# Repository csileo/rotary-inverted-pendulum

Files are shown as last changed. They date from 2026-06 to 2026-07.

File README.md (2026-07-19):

# Rotary Inverted Pendulum

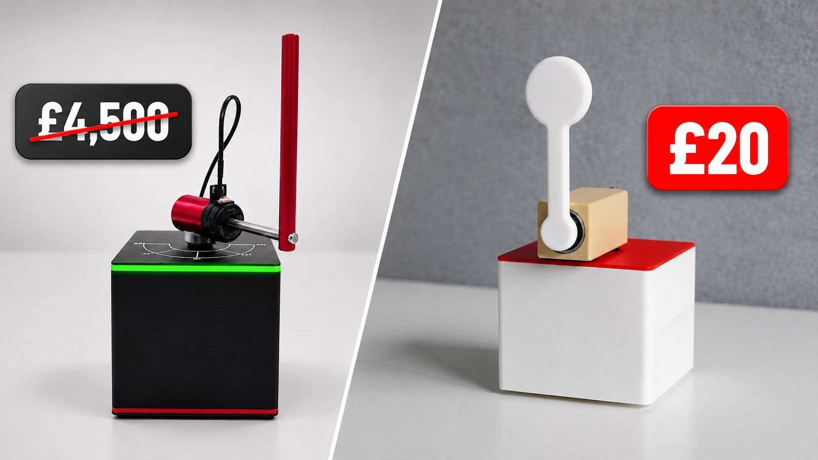
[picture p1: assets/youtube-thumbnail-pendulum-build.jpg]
Watch the build video (https://www.youtube.com/watch?v=rKChjuuR7K8)


A DIY rotary inverted pendulum you can print, solder, and train at home — for about **£20** in parts. It's an open, hackable take on the rigs you'd usually buy from a lab-equipment vendor (Quanser's [QUBE Servo 2](https://www.quanser.com/products/qube-servo-2) lists at around £4,500). The pendulum balances itself with a reinforcement-learning policy trained in simulation, fine-tuned on the real hardware, and quantised to run on an Arduino Nano.

## What's in this repo

| Directory | Contents |
| --- | --- |
| [`meshes/`](meshes), [`urdf/`](urdf) | 3D-printable STLs and the URDF model (single source of truth for pendulum geometry) |
| [`diagrams/`](diagrams) | Wiring diagrams and component photos |
| [`RotaryInvertedPendulum-arduino/`](RotaryInvertedPendulum-arduino) | Firmware — low-level server, hand-tuned PID, on-device RL controller |
| [`RotaryInvertedPendulum-python/`](RotaryInvertedPendulum-python) | Sim env, SAC training, system identification, real-hardware bridge, distillation and int8 export |
| [`RotaryInvertedPendulum-julia/`](RotaryInvertedPendulum-julia) | MPC/LQR exploration and MeshCat visualisation |
| [`docs/`](docs) | Build runbook, BOM, electronics design, RL stack documentation |

## Where to start

- **Build one** — [`docs/BOM.md`](docs/BOM.md), [`docs/electronics_design.md`](docs/electronics_design.md), [`docs/end_to_end_runbook.md`](docs/end_to_end_runbook.md)
- **Train a policy** — [`RotaryInvertedPendulum-python/README.md`](RotaryInvertedPendulum-python/README.md) walks through the simulation and training pipeline
- **Understand the RL stack** — [`docs/rl_transitions.md`](docs/rl_transitions.md), [`docs/domain_randomization.md`](docs/domain_randomization.md), [`docs/transport_delay.md`](docs/transport_delay.md), [`docs/quantisation.md`](docs/quantisation.md), [`docs/sysid_runbook.md`](docs/sysid_runbook.md)

## Branches

`main` has everything, including the trained checkpoints. Four narrower branches exist for handing off less than the whole thing:

| Branch | Contents |
| --- | --- |
| `2-full-no-models` | Everything except `models/` and `logs/` |
| `3-rl-ready` | Just the RL pipeline ([`RotaryInvertedPendulum-python/src/rl/`](RotaryInvertedPendulum-python/src/rl)) — run the training scripts as-is |
| `4-diy-rl` | Just the physical parameters ([`sysid_params.json`](RotaryInvertedPendulum-python/src/rl/sysid_params.json), [`docs/rig_geometry_parameters.md`](docs/rig_geometry_parameters.md)) — write your own sim and training from scratch |
| `demo` | Just enough to run the best checkpoint on the rig |

## Prefer to buy rather than build?

DIY kits run [$100–$200 on AliExpress](https://www.aliexpress.com/w/wholesale-rotary-inverted-pendulum.html); the Quanser QUBE Servo 2 mentioned above is around £4,500.

## Related work

- [Desktop Inverted Pendulum, build-its-inprogress](https://build-its-inprogress.blogspot.com/2016/08/desktop-inverted-pendulum-part-2-control.html) ([full series](https://build-its-inprogress.blogspot.com/search/label/Pendulum))
- [Furuta pendulum, dagor.dev](https://www.dagor.dev/blog/furuta-pendulum)
- [The Rotary Control Lab — Quanser brochure (PDF)](https://tecsolutions.us/sites/default/files/quanser/The%20Rotary%20Control%20Lab%20Brochure_4.pdf)
- [Survey paper, *Trans. Inst. Meas. Control*](https://journals.sagepub.com/doi/full/10.1177/00202940211035406)
- Video builds: [[1]](https://www.youtube.com/watch?v=2koXcs0IhOc), [[2]](https://www.youtube.com/watch?v=bY4t6yfBA24), [[3]](https://www.youtube.com/watch?v=VVQ-PGfJMuA)

## Acknowledgments

I would like to thank the following people for their contributions to this project:
- [Joe](https://github.com/spookycouch) for suggesting I try reinforcement learning with Stable Baselines 3, which kicked off the learned-control parts of this project.
- [Mykha](https://github.com/Mika412) for early discussions about this project over a beer in the park.
- [André](https://github.com/Esser50K), [Rafael](https://github.com/rkourdis), and [Vlad](https://github.com/VladimirIvan) for technical discussions, feedback, and support.
- [Vivek](https://github.com/svrkrishnavivek) for his invaluable help and feedback on the electronics of the system.
- [心诺 (Xinnuo)](https://github.com/XinnuoXu) for her company and support while working on this project.

Finally, I would like to thank the open-source community in general for providing the tools and resources that have also helped make this project possible.

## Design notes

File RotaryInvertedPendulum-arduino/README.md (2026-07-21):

# Arduino Sketches

This folder contains Arduino sketches for the Rotary Inverted Pendulum project.

## Prerequisites

Install [arduino-cli](https://arduino.github.io/arduino-cli/latest/installation/) and the AVR core:

```bash
arduino-cli core install arduino:avr
```

## Flashing Sketches

1. Find your Arduino's serial port:
   ```bash
   arduino-cli board list
   ```

2. Compile and flash (from repository root):
   ```bash
   arduino-cli compile --upload -p <PORT> --fqbn arduino:avr:nano:cpu=atmega328 RotaryInvertedPendulum-arduino/<SketchName>
   ```

   **Note:** This project uses `cpu=atmega328` (new bootloader). Do not use `cpu=atmega328old`.

## Sketches

### Test Sketches

These sketches are for testing individual hardware components.

#### TestHeartbeat

Blinks the LED in a double-pulse pattern. Useful for verifying the Arduino is powered and running.

- **Pattern:** ON(100ms)-OFF(100ms)-ON(100ms)-OFF(1000ms), repeating
- **Serial (115200):** Shows heartbeat count

**Use cases:** Quick hardware verification, power testing, bootloader check, debugging baseline.

#### TestEncoder

Tests the AS5600 magnetic encoder with multi-revolution tracking.

- **LED on** during setup, waits for magnet detection
- **LED flashes** when outputting readings
- **Serial (115200):** Outputs `pendulum_deg:value` (compatible with Serial Plotter)

**Troubleshooting:**
- "Waiting for magnet..." → Ensure magnet is positioned near the AS5600 sensor
- "Magnet strength too weak/strong" → Adjust magnet distance (~1-2mm)

#### TestMotor

Tests the stepper motor by oscillating between +90° and -90° positions.

- **LED on** during setup and during movement
- **Serial (115200):** Shows movement status
- Max speed set to 20,000 steps/sec (10x slower than production for visibility)

#### TestSerial

Measures serial round-trip time by echoing bytes.

- **LED on** during setup
- **LED flashes** on each received byte

Run the Julia measurement script:
```bash
julia --project=./RotaryInvertedPendulum-julia ./RotaryInvertedPendulum-arduino/TestSerial/measure_serial_rtt.jl <PORT> 115200
```

Expected output: ~2.5ms RTT, ~400 Hz max theoretical frequency.

#### TestServer

Simple server that tracks sine/cosine waves and responds to 'S' or 'C' byte requests.

```bash
julia --project=./RotaryInvertedPendulum-julia ./RotaryInvertedPendulum-arduino/TestServer/client.jl
```

### Production Sketches

#### LowLevelServer

Low-level server for computer-controlled operation. Arduino acts as a slave, receiving commands over serial (2,000,000 baud) from Julia/Python control code.

```bash
julia --project=./RotaryInvertedPendulum-julia ./RotaryInvertedPendulum-arduino/LowLevelServer/client.jl --visualise
```

**Before compiling**, copy the AS5600 backend matching your encoder module
from `LowLevelServer/hw_profiles/` to `LowLevelServer/hw_config.h`
(gitignored — no safe default, see that directory's files and
`docs/BOM.md` for which module you likely have):

```bash
cp LowLevelServer/hw_profiles/as5600_hailege_clone.h LowLevelServer/hw_config.h  # Hailege clone
# or
cp LowLevelServer/hw_profiles/as5600_seeed.h LowLevelServer/hw_config.h          # genuine Seeed module
```

`tools/pi_demo/flash_if_needed.py` refuses to compile without this file present.

#### PIDControl

Self-contained PID controller running entirely on Arduino. No computer required after flashing.

- **Serial (500000 baud):** Connect to view diagnostics and collect data
- **LED blink rate:** Fast (100ms) = waiting, Slow (500ms) = data output enabled

**Serial commands:**
- `P` - Toggle data output (CSV format at 100 Hz)
- `M` - Show magnet status
- `R` - Reset PID state

**Data collection:**
```bash
julia --project=./RotaryInvertedPendulum-julia ./RotaryInvertedPendulum-arduino/PIDControl/collect_and_plot.jl <PORT> [DURATION]
```

Example:
```bash
julia --project=./RotaryInvertedPendulum-julia ./RotaryInvertedPendulum-arduino/PIDControl/collect_and_plot.jl /dev/cu.usbserial-10 10
```

This collects data for the specified duration, generates plots, and saves CSV to `PIDControl/experiments/`.

See `PIDControl/TUNING_HISTORY.md` for tuning notes and `PIDControl/PIDControl.ino` header for architecture details.

## Hardware-in-the-Loop Testing

For automated testing with hardware connected:

```bash
./RotaryInvertedPendulum-arduino/scripts/monitor_serial.sh <PORT> <BAUD> <DURATION>
```

Example:
```bash
./RotaryInvertedPendulum-arduino/scripts/monitor_serial.sh /dev/cu.usbserial-10 115200 10
```

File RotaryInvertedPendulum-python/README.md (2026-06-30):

# RotaryInvertedPendulum-python

Python tooling for the rotary inverted pendulum: gamepad control,
system identification, and the RL pipeline (env, SAC trainer, deployment
client). See [`../RL_PLAN.md`](../RL_PLAN.md) for the broader plan.

## Environment setup

Single mamba env named `rotary-inverted-pendulum`, Python 3.12. Conda-forge
provides the scientific stack; pip provides MuJoCo / Gymnasium / SB3 / Torch
because they are more reliably installed from PyPI.

```bash
mamba create -n rotary-inverted-pendulum -y -c conda-forge python=3.12 numpy scipy
mamba activate rotary-inverted-pendulum

# Gamepad demo (older text-protocol script)
mamba install -y pygame pyserial

# RL + sysid extras (PyPI)
pip install pyserial 'numpy<2.3' mujoco gymnasium 'stable-baselines3[extra]'
```

Notes:
- `numpy<2.3` keeps compatibility with the conda-installed `scipy 1.14`. If
  you hit `_ARRAY_API not found` errors, an older `opencv-*` in
  `~/.local/lib/python3.12/site-packages/` is shadowing the env install.
  Run `pip install --user --upgrade opencv-contrib-python` to refresh it.
- macOS only: the MuJoCo viewer requires `mjpython` (a special launcher that
  handles Cocoa main-thread quirks). Install via the same `pip` and call
  `mjpython` instead of `python` for any script that opens a viewer.

## Control rate

This rig's canonical operating rate is **35 Hz** (28.6 ms per control step,
`max_action_delta_rad = 0.10` → 3.5 rad/s slew). It's the empirically-best
operating point on this hardware: 100 Hz pushes the policy into a noisy
"active correction" attractor where the motor swings ±0.5 rad even when
balanced; 30 Hz lacks slew authority for disturbance recovery; 35 Hz lands
in the calm-attractor side of the boundary at slew ~3.5 rad/s.

All `--control-freq` flags and the `control_freq_hz` constructor defaults
across `pendulum_env.py`, `real_env.py`, `async_control.py`, `train_sac.py`,
`finetune_async.py`, `eval_randomized.py`, `run_policy.py`, and `distill.py`
default to 35 Hz. Override only if you have a reason — see
[`../docs/control_rate_selection.md`](../docs/control_rate_selection.md) for
the principled rate-window argument and the calm-vs-active attractor data.

## End-to-end pipeline

For the full sysid → sim training → real-rig fine-tune → distill → flash
walkthrough with exact commands at each step, see
[`../docs/end_to_end_runbook.md`](../docs/end_to_end_runbook.md). Each step
is idempotent, so you can also dip into individual phases without re-running
the whole pipeline.

## Workflows

### Gamepad control (legacy)

Drives the Arduino's text-protocol firmware.

```bash
python src/gamepad_control.py
```

### System identification

Phase 0 of the RL plan. See [`../docs/sysid_runbook.md`](../docs/sysid_runbook.md)
for the full protocol. Quick start (with `LowLevelServer.ino` flashed):

```bash
cd src/rl
python sysid_wizard.py                  # full pipeline: collect + fit + plots
python sysid_wizard.py fit --in-dir ... # re-fit existing logs (no rig)
```

Re-run sysid whenever the rig changes (rebuilds, new bearings, motor envelope
adjustments, etc.) so `sysid_params.json` stays current and the simulator
reflects reality.

### RL training (Phase 1+)

Trains an SB3 SAC policy against the MuJoCo env parameterised by
`sysid_params.json`. Single env on CPU is the default; vectorised envs and
GPU are available via flags.

```bash
cd src/rl
python train_sac.py --total-steps 500000 --progress-bar
# View training curves
tensorboard --logdir runs/
```

Resume / evaluate:

```bash
python train_sac.py --resume runs/<run>/last.zip --total-steps 1000000
mjpython train_sac.py --eval runs/<run>/best_model.zip --eval-seconds 30
```

### Curriculum training (recommended)

Training from scratch with the full target DR (4-7 step delay, etc.) is
hard for SAC to converge — the policy gets stuck early. The curriculum
runner trains the policy in three stages of increasing DR difficulty,
each `--resume`-ing from the previous one's `best_model.zip`.

```bash
./curriculum_train.sh <run-name-prefix>
# example -> runs/<prefix>_stage1, _stage2, _stage3
```

Stage breakdown (defined in `curriculum_train.sh`):

| Stage | tau range | delay range | steps |
|---|---|---|---|
| 1 (easy) | 0–5 ms  | 0–2 steps | 100k |
| 2 (medium) | 0–10 ms | 2–5 steps | 100k |
| 3 (final)  | 0–10 ms | 4–7 steps | 100k |

The final stage 3 delay range matches the hardware's measured 5-step
transport delay at `MOTOR_ACCELERATION = 50k` and `Vref = 0.45 V`.
Override per-stage parameters via env vars (`SEED`, `STEPS_PER_STAGE`,
`DEVICE`).

### Evaluating a policy

Two complementary tools:

```bash
# Render a deterministic eval rollout in the MuJoCo viewer (mjpython on macOS)
mjpython train_sac.py --eval runs/<run>/best_model.zip --eval-seconds 30

# Stress-test the policy on N=20 randomly-physics-configured episodes.
# Reports a per-episode ✓/✗, a "solved" success rate, and the underlying
# DR sample (tau, delay) used for each episode. See the script docstring
# for the full success-criterion definition.
python eval_randomized.py runs/<run>/best_model.zip --n-episodes 20
```

### Trajectory logging + sim-to-real analysis

`run_policy.py --log <path>.npz` saves a step-level trajectory of the real-
hardware run. Two helper scripts then introspect that log to fit refined
sysid against the actively-driven dynamics (typically more informative
than the chirp/step sysid alone):

```bash
# Rough fit of effective transport delay and first-order tau against
# motor_target → motor_actual.
python analyze_run.py /tmp/policy_run.npz

# Replay the same logged action sequence in the sim and report motor /
# pendulum trajectory error vs the real device. Shows you how big the
# sim-to-real gap actually is on a real run.
python sim_vs_real.py /tmp/policy_run.npz
```

### Real-hardware deployment (Phase 3)

Drives the Arduino's `LowLevelServer.ino` binary protocol. Re-flash the
Arduino with `LowLevelServer` (sysid uses a different sketch). Always run
`--dry-run` first to verify the protocol; then run engaged with the rig
supervised.

```bash
cd src/rl
python run_policy.py --policy runs/<run>/best_model.zip \
    --port /dev/cu.usbserial-1130 --duration-s 5 --dry-run
python run_policy.py --policy runs/<run>/best_model.zip \
    --port /dev/cu.usbserial-1130 --duration-s 5
```

The deploy client clamps commanded position to ±125° (inside the ±135°
mechanical hard stops) and disengages the motor on exit / SIGTERM /
SIGINT.

## Layout

```
src/
  gamepad_control.py        # legacy text-protocol gamepad control
  rl/
    pendulum_env.py         # Gymnasium env (MuJoCo) parameterised from sysid_params.json
    train_sac.py            # SB3 SAC trainer with eval+checkpoint callbacks
    curriculum_train.sh     # 3-stage curriculum runner (easy -> full DR)
    eval_randomized.py      # N-episode randomized-env stress test (success-rate metric)
    run_policy.py           # Phase 3 deployment client (binary protocol)
    analyze_run.py          # Fits effective tau / transport delay from a run_policy log
    sim_vs_real.py          # Replays a logged action sequence in sim and compares
    lowlevel_client.py      # Python client for LowLevelServer.ino
    sysid_wizard.py         # Interactive sysid (collect/fit/validate-motor)
    sysid_core.py           # Sysid math (fits + parameter derivation)
    sysid_params.json       # Output of sysid_wizard.py (committed)
    freeswing_probe.py      # Standalone sim-vs-real validator
    sysid_runs/             # Per-session recordings (gitignored)
    runs/                   # Training artifacts (gitignored)
test/
  serial_test.py            # bare serial sanity check
  gamepad_test.py           # gamepad sanity check
```

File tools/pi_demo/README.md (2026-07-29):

# Auto-demo launcher

Makes the "power it on, walk away, it balances" demo robust to whatever
order the person plugs in the Pi/computer's power, the pendulum's 12V
adapter, and the Nano's USB cable in — and to arbitrary delay between each.
Nothing here assumes a particular order; each step waits out its own
precondition instead of failing on the first miss.

Runs unchanged on Linux, macOS, and Windows: the Nano is found by scanning
USB devices for its vid/pid (via `pyserial`'s `serial.tools.list_ports`)
instead of relying on a fixed `/dev/ttyUSB0`-style path or a udev rule, and
the launcher itself is plain Python rather than a shell script.

- **`flash_if_needed.py`** — waits for the Nano to show up, then compares
  a hash the firmware reports (`CMD_GET_FIRMWARE_VERSION`, baked in at
  compile time by
  `RotaryInvertedPendulum-arduino/LowLevelServer/gen_firmware_version.py`)
  against the local sketch source. Only runs `arduino-cli compile
  --upload` on a mismatch (or no response at all) — skips the ~15-30s
  flash cycle on every normal boot where the Nano already has the right
  firmware. Refuses to compile at all if
  `RotaryInvertedPendulum-arduino/LowLevelServer/hw_config.h` is missing
  (see that directory's `hw_profiles/`) — there's no safe default AS5600
  backend to guess.
- **`check_motor_power.py`** — the rig has no voltage sensing on the 12V
  rail, so this checks it indirectly: issue a small, brief acceleration
  pulse and confirm the AS5600 actually saw the motor move. If it didn't,
  the 12V adapter isn't plugged in (or there's a driver/Vref/enable wiring
  fault) — no new sensing hardware required.
- **`run_demo.py`** — orchestrates the above in order, waiting (not
  failing) at each step until its precondition is met, then runs the
  policy. Loops forever (10s pause between cycles by default) so a
  headless/no-network Pi keeps re-demoing without anyone reconnecting to
  restart it — Ctrl-C or SIGTERM (`systemctl stop`) is the only way out.
  Loads the policy once and keeps one serial connection to the Nano open
  across every cycle (calling `run_policy.py`'s `run_control_loop()`
  in-process instead of launching it as a fresh subprocess each time) —
  opening a new connection resets the Arduino, so reusing one avoids
  paying that reset repeatedly. The connection is only rediscovered /
  reflashed / reopened if something actually goes wrong (e.g. the Nano
  gets unplugged). Defaults `PENDULUM_POLICY` to the `.npz` (NumPy-only)
  build of the distilled student, not the `.pt`/torch one, so this
  process never has to import torch at all — see `numpy_student.py`.

## Which Nano to talk to

`pi_demo_common.py` resolves the vid/pid to search for like this:

1. `usb_config.json` in this directory, if it exists — this machine's own
   detected chip, written by `detect_usb_config.py`.
2. Otherwise, `usb_profiles/ch340.json` — the tracked reference default
   (confirmed in `docs/BOM.md` for both known builds).

`usb_config.json` is gitignored: it's a fact about this specific machine's
USB-serial chip, not something to share across forks. **The only way to
change which chip is used is to overwrite `usb_config.json`** — there is
no environment variable or CLI flag override, so it can never silently
drift out of sync with what's actually plugged in.

If your Nano uses a different chip than CH340/CH341, either add a new
`usb_profiles/<name>.json` (same two-key format) and copy it to
`usb_config.json`, or just run `detect_usb_config.py` with only the Nano
plugged in — it detects whichever single USB-serial device is present and
writes `usb_config.json` directly.

## Setup

1. Install Python deps (repo root `requirements.txt`, or the `demo`
   branch's copy if this is a demo-only checkout) and make sure
   `arduino-cli` is on `PATH` for the flash step.
2. Run `python detect_usb_config.py` once, with only the Nano plugged in
   (skip this if your chip already matches `usb_profiles/ch340.json`).
3. Make sure `RotaryInvertedPendulum-arduino/LowLevelServer/hw_config.h`
   is set up for your AS5600 module (see that directory's README/comments).
4. Run it: `python run_demo.py`. Wire it to whatever "on demand" trigger
   you want — a systemd service on the Pi, a Scheduled Task on Windows, a
   physical button via a GPIO watcher, cron, etc. This repo doesn't
   prescribe one; the script is a plain foreground process that loops
   forever (see above), blocking until Ctrl-C/SIGTERM.

## Environment variables

All optional — see `run_demo.py` for the exact defaults. None of these
select which Nano to talk to (see above) — only what to run once it's found.

| Variable | Meaning |
|---|---|
| `PENDULUM_POLICY` | Path to the `.zip`/`.pt`/`.npz` checkpoint to run |
| `PENDULUM_FRAME_STACK` | Must match the checkpoint's training frame-stack |
| `PENDULUM_DURATION_S` | How long to balance before stopping (default 30s) |
| `PENDULUM_MOTOR_POWER_TIMEOUT_S` | How long to wait for 12V before giving up |
| `PENDULUM_LOOP_DELAY_S` | Pause between demo cycles (default 10s) |
| `PENDULUM_CONTROL_FREQ_HZ` | Control loop frequency, must match training (default 35.0) |
| `PENDULUM_MAX_ACCEL_RAD_S2` | Action-to-acceleration scale, must match training (default 150.0) |

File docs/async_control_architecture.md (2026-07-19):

# Async Control Architecture

How `finetune_async.py` keeps the rig's control loop at strict 100 Hz
(or any configured rate) while SAC's gradient updates run in parallel.
This is a runtime-systems doc — it has no opinions about RL semantics
(see [`rl_transitions.md`](rl_transitions.md) for those) or how to
*choose* a control rate (see [`control_rate_selection.md`](control_rate_selection.md)
for that). It only explains how we *enforce* whatever rate was chosen.

## The bug this exists to prevent

During Phase 4 fine-tuning we discovered that SB3's `SAC.learn()` runs
`collect_rollouts` (which calls `env.step()`) and `train()` (gradient
updates) sequentially in **one thread**. With `--gradient-steps 4`,
gradient updates take ~20 ms per env step. The env's pacing logic
(`time.sleep(next_tick - monotonic())`) silently dropped the configured
100 Hz to ~35 Hz actual. The policy *learned 35 Hz dynamics*. Deployment
at 100 Hz produced motor chatter and step-skipping — same weights,
totally different observed behavior.

`finetune_async.py` is the architectural fix: a custom training loop
(replacing `model.learn()`) that owns two cooperating threads.

## Two threads

```
┌──────────────────────────────────────────┐    ┌──────────────────────────────────┐
│ Control thread (background, strict 100Hz)│    │ Learner thread (main, best effort)│
│                                          │    │                                  │
│ every 10 ms:                             │    │ loop:                            │
│   action ← snapshot.predict(obs)         │    │   transitions ← queue.drain()    │
│   env.apply_action(action)               │    │   for t: replay_buffer.add(t)    │
│   sleep_busywait_until_next_tick()       │ →→ │   if past warmup:                │
│   next_obs ← env.observe_and_step(...)   │    │     model.train(K, batch_size)   │
│   queue.put(transition)                  │    │     snapshot.refresh_from(actor) │
│                                          │    │                                  │
└──────────────────────────────────────────┘    └──────────────────────────────────┘
            │                                                 │
            ↓                                                 ↓
        TransitionQueue (deque + lock) — producer/consumer between threads
                                                              │
                                                              ↓
                                              model.replay_buffer (SB3 ReplayBuffer)
```

The control thread **never blocks on the learner**. The learner **never
blocks on the rig**. They communicate through one shared queue and one
shared replay buffer, both lock-protected.

## Three locks

1. **`LowLevelClient._lock`** (per-serial-transaction). Prevents
   interleaved bytes when the control thread is mid-`get_state` and
   the main thread fires `disengage_motor` for safety.

2. **`replay_buffer_lock`** (orchestrator-owned). Held during
   `replay_buffer.add()` *and* during the entire `model.train(K, batch)`
   call. SAC's `train()` calls `sample()` K times internally; we want a
   frozen view across those calls. In practice contention is zero —
   both contenders are on the main thread; the lock exists for
   future-proofing and audit trail.

3. **`PolicySnapshot._lock`**. Guards `self._net.load_state_dict(...)`
   (called by the learner after `train()`) versus `self._net(obs)`
   (called by the control thread). **Required**: PyTorch's
   `optimizer.step()` mutates parameter `.data` in place, and a forward
   pass concurrent with that write would yield a corrupted action. The
   snapshot is a deepcopy of `model.actor`; the learner's working actor
   is untouched by the control thread.

## Why a snapshot, not the live actor?

If the control thread called `model.actor(obs)` directly, every
inference would race with whichever step of `optimizer.step()` happened
to be running on the learner. Reading partially-updated parameters
gives a corrupted action — fine in a benchmark, dangerous when it
drives a motor. The snapshot adds a one-`state_dict`-copy cost per
train cycle (microseconds) and gives consistent reads.

## Pacing — the busy-wait detail

macOS `time.sleep` typically overshoots by 1-2 ms (no `SCHED_FIFO`).
A naive sleep-the-full-remainder pattern yields a mean rate of ~83 Hz
when you ask for 100 Hz. The fix is two-stage:

```python
sleep_for = next_tick - time.monotonic()
if sleep_for > 0.001:
    time.sleep(sleep_for - 0.001)
while time.monotonic() < next_tick:
    pass    # busy-wait the last ≤ 1 ms
```

Adds <1% CPU at 100 Hz, pulls jitter from ~2 ms down to <0.1 ms.
Standalone V1/V2 tests measure mean dt = 10.000 ms, std < 1 ms.

## Watchdog: the 3-strike timing rule

Inside the tick loop, if the control thread overruns its deadline
by more than `timing_violation_threshold_ms` (default 5 ms) for **3
consecutive** ticks, `AsyncControlLoop` disengages the motor and
raises `TimingViolation`. Three-strike tolerance because macOS
schedulers occasionally hiccup once and recover; three-in-a-row is
structural (probably the learner thread is holding the GIL too long).

This is how future users learn about the bug *quickly* if they
misconfigure things — no more silent rate drops.

When raising, the loop also calls `queue.discard_recent(max_strikes - 1)`
so transitions queued during the violating ticks (with stretched dt)
don't pollute the replay buffer.

## Signal handling

Python only delivers signals to the main thread. The orchestrator
installs `SIGINT`/`SIGTERM` handlers that:

1. Set the shared `stop_flag` (which the control thread polls at the
   top of every tick → exits cleanly).
2. Call `env.disengage_safely()` (which uses `LowLevelClient._lock`
   to safely write the disengage byte even if the control thread is
   mid-read).

The synchronous `RealRotaryInvertedPendulumEnv.__init__` no longer
auto-registers signal handlers — that was load-bearing for the old
sync flow but conflicts with multi-threaded ownership. Direct callers
who want the old behavior can wire `signal.signal(SIGINT, env._on_signal)`
themselves.

## Replay buffer persistence

`finetune_async.py` saves `runs/<run-name>/replay_buffer.pkl` (~6 MB
per 30 k transitions, pickle) at session end and at every checkpoint.
The `--resume-buffer <path>` flag lets a future session load it via
`model.load_replay_buffer`. This means real-robot transitions
**accumulate across sessions** instead of being discarded each time —
critical because real-robot data is ~1000× more expensive to collect
than sim data.

Important: do **not** load buffers from synchronous fine-tunes
(legacy `finetune_real.py`). Those transitions describe `(s, a, s')`
at variable 28-30 ms intervals (see "the rate-mismatch bug" above).
Mixing them with the new strict-rate transitions teaches the critic
contradictory mappings. Same caveat for buffers from a different
control rate — always resume against the same rate the buffer was
collected at.

## Verification protocol

Implemented and run in this order — each step proves a property in
isolation before composing:

- **V1**: control loop alone with no-op learner → mean dt = 10.000 ms,
  std < 1 ms. Proves the control thread alone holds 100 Hz on macOS.
- **V2**: control loop with synthetic CPU-hog learner → identical
  timing. Proves the learner doesn't perturb the control thread via
  the GIL.
- **V3** (rig required): real `model.train(K=4)` with a pre-loaded
  buffer → identical timing. Proves PyTorch + numpy + optimizer step
  doesn't starve the control thread.
- **V4** (rig required): short end-to-end fine-tune (10 episodes × 6 s,
  K=4) — orchestrator-reported mean tick rate within ±2 Hz of target,
  zero violations, redeployed policy doesn't chatter at the same rate.
- **V5** (rig required): full re-baseline — fresh sim curriculum at
  the chosen design rate, then a clean fine-tune. Final policy must
  show sustained balance windows ≥ 5 s in deployment runs.

Per-episode telemetry is logged to `runs/<run-name>/timing.csv`:
`mean_tick_dt_ms`, `std_tick_dt_ms`, `max_overrun_ms`, `n_violations`,
`learner_train_calls`, `learner_total_train_s`. This is the artifact
that proves we don't regress in future PRs.

## Where it lives in code

| File | What it does |
|---|---|
| `async_control.py` | `TransitionQueue`, `PolicySnapshot`, `AsyncControlLoop`. Pure runtime primitives — no SB3 references except for accepting an `nn.Module` to snapshot. |
| `finetune_async.py` | The orchestrator: loads SAC, manages threads + locks, handles signals, persists buffer + policy. |
| `lowlevel_client.py` | `_lock` added so concurrent `get_state` / `disengage_motor` calls don't interleave bytes. |
| `real_env.py` | `apply_action` and `observe_and_step` split out of the synchronous `step` so the async loop can interleave them with externally-paced sleeps. |

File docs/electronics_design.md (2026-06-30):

# Electronics Design Notes

Why each component on the [BOM](BOM.md) was chosen, and what to know
when re-sourcing or substituting it. The BOM is the procurement
reference; this doc is the *why* behind it.

## Wiring diagram



All components live on a single 40 × 60 mm protoboard. The diagram
above is the canonical layout; component-level photos are in
[`../diagrams/`](../diagrams/).

## Microcontroller — Arduino Nano (ATmega328P, 16 MHz)

- 32 KB flash / 2 KB SRAM is enough for the [LowLevelServer binary
  protocol](../RotaryInvertedPendulum-arduino/LowLevelServer/LowLevelServer.ino)
  plus AS5600 I/O plus AccelStepper at 1 kHz internal step rate. The
  on-device PID variant fits too, with margin.
- Heavy lifting (RL inference, MPC, sysid) runs on the host PC. The
  Nano shuttles state and commands at 2 Mbaud — it doesn't need MCU
  horsepower.
- USB-C variant preferred over Mini/Micro for connector durability —
  the rig gets re-plugged frequently during firmware iteration.
- Any CH340-based clone works; driver is built into modern macOS / Linux.

## Stepper motor — NEMA17 17HS4023 (1 A rated, 22 mm body)

- **Under-loaded by design.** The arm + pendulum is <50 g and the only
  rotational inertia the motor fights is the arm itself (~1.5 × 10⁻⁵
  kg·m²). Phase current rarely exceeds ~0.3 A. The 1 A rating is
  ~3× headroom against ever stalling.
- **Short-body 17HS4023 over the longer 17HS4401.** The motor is
  bolted vertically, so its mass is below the rotation axis and
  doesn't load the bearings — but the shorter body still trims rig
  height and cost. With the loads this rig sees, the longer motor's
  extra torque is wasted.
- Substituting a heavier or stronger motor would add mass and cost
  without benefit; substituting a smaller one (e.g. NEMA14) risks
  losing steps under sudden swing-up commands.

## Stepper driver — DRV8825

- **Vref set to 0.45 V → ~0.9 A current limit** per phase (90 % of
  the motor's 1 A rating). Standard 10 % margin keeps the driver and
  motor below thermal limits indefinitely.
- 8.2–45 V supply range; 12 V chosen as the lowest sensible voltage —
  see "Power supply" below.
- **A4988** is a drop-in alternative but tops out at lower current and
  is audibly louder.
- **TMC2209** would be quieter via internal interpolation but adds UART
  configuration complexity for negligible benefit on this rig: the 8×
  microstepping output from AccelStepper is already smooth at the
  speeds we run.
- **Set Vref before installing the motor.** With the driver powered
  and the motor disconnected, probe Vref against GND while turning
  the trim pot.

### Vref for alternative drivers

If you swap to A4988 or TMC2209, the Vref-trim procedure is the same
but the relation between Vref and the resulting phase-current limit
differs:

| Driver  | Imax → Vref | Vref @ 0.9 A target |
| --- | --- | --- |
| DRV8825 | `Vref = Imax / 2` (Rcs = 0.1 Ω, standard on Pololu and most clones) | **0.45 V** (we run 0.45 V — close enough) |
| A4988 | `Vref = Imax × 8 × Rcs`. Pololu carriers use Rcs = 0.05 Ω; some clones use 0.1 Ω — check yours | **0.36 V** (Pololu) / **0.72 V** (Rcs = 0.1 Ω clones) |
| TMC2209 | RMS-current calc is non-trivial — use the [TMC220X Vref calculator](https://printpractical.github.io/VrefCalculator/) | per calculator |

## Power supply — 12 V, 2 A

The ideal supply for this rig. Reasoning:

The DRV8825 chops coil current, so supply current ≠ motor phase
current. Power balance:

```
I_supply ≈ (I_phase × V_coil) / V_supply
        ≈ (0.9 A × ~3.5 V) / 12 V ≈ 0.26 A per phase
```

Both phases active plus ~50 mA of logic (Nano + AS5600 + indicators)
gives **~0.6 A steady-state**, with brief peaks to ~1 A on direction
reversals. 2 A is ~3× headroom — the right margin for a cheap
wall-wart with no wasted capacity.

3 A and 5 A adapters work fine (verified empirically) but the extra
current is unused. What actually matters more than headline amps:

- **Regulation quality** — a clean 2 A unit beats a noisy 5 A one for
  ripple. The Nano's 5 V LDO and the AS5600's I²C bus get unhappier
  with messy rails than with low-rated ones.
- **Bulk decoupling on the board** — the 22 µF on the rail handles
  the worst of the chopping spikes. If you ever see brown-outs on
  direction reversals, add a 470 µF near the driver before upsizing
  the adapter.
- **Connector contact** — a loose 5.5 mm barrel jack drops volts under
  spike load regardless of adapter rating.

**Why 12 V** specifically:
- DRV8825 accepts 8.2–45 V; 12 V is the cheapest sensible choice.
- The Nano's onboard linear regulator dissipates 12 V → 5 V
  comfortably. 24 V starts to cook it (the regulator runs hot enough
  to derate above ~16 V continuous).
- 12 V wall-warts with 5.5 mm barrel plugs are ubiquitous.

## Magnetic encoder — AS5600

- **12-bit absolute angle** → 2π / 4096 rad ≈ 0.088° resolution.
  Quantisation is modelled in [`pendulum_env.py`](../RotaryInvertedPendulum-python/src/rl/pendulum_env.py)
  (`PENDULUM_LSB_RAD`) so the policy sees the same step size sim
  and real.
- **Contactless / magnetic** → zero friction on the pendulum joint,
  which is the mechanical DOF we most care about preserving. A
  contact pot or quadrature wheel would add a friction term we'd
  have to identify and randomize against.
- I²C at 400 kHz reads in <1 ms — fits comfortably in the control budget.
- The TZT-style AliExpress modules ship with a small diametrically-
  magnetised disc; no separate magnet sourcing needed.
- **Magnet alignment matters.** Disc face 0.5–3 mm from chip face,
  axially aligned. The AS5600's `AGC` (automatic gain control)
  register reports magnet strength — check it on first power-up;
  out-of-range readings indicate a misaligned or wrong-grade magnet.

## Decoupling — 100 nF ceramic + 22 µF electrolytic

Two-stage decoupling on the 12 V rail at the driver's VMOT pin:

- **100 nF ceramic (104)** handles high-frequency spikes from the
  driver's ~30 kHz chopping. The ceramic's low ESR matters more than
  its capacity at this point.
- **22 µF electrolytic** handles bulk current draw between switching
  cycles. 22 µF is fine for this rig's modest loads; if you upsize
  the motor or see brown-outs on fast reversals, bump to 470 µF
  before upsizing the supply.

## Hookup wire — 26 AWG solid-core

- Single gauge across signals + power, because:
  - Rig peak current is ~1 A; 26 AWG handles 2.2 A continuously in
    chassis wiring.
  - One stock is easier to manage than separate gauges for signal vs
    power, and the difference doesn't matter at these currents.
  - Solid-core terminates more reliably in protoboard plated holes
    than stranded.
- A dedicated thinner gauge for I²C would be overkill at the AS5600
  cable's ~100 mm length.

## Power switch + barrel jack

- An **inline SPST rocker** on the 12 V rail is far more convenient
  than yanking the barrel plug. Power-cycling is a frequent diagnostic
  during firmware development.
- **Jack/plug size mismatch** (5.5 × 2.1 mm jack vs 5.5 × 2.5 mm
  adapter plug): the 0.4 mm pin-diameter difference produces a slightly
  loose fit but reliable contact in practice. If you can find a
  matched 2.5 mm jack at the same price, prefer it — otherwise the
  mismatch is harmless.

## Things deliberately *not* on the BOM

- **Battery / boost converter.** This rig is computer-tethered for the
  RL pipeline; portability isn't a goal. The on-device PID firmware
  *could* be battery-powered, but cheap LiPo + buck is more
  diagnostics surface than the use case warrants.
- **TVS / protection diodes on the rail.** The wall-wart adapters used
  here are well-behaved; an RC snubber on the motor leads or a TVS at
  VMOT would be belt-and-braces but isn't load-bearing for stable
  operation.
- **Logic-level shifters.** Nano (5 V) + AS5600 (3.3 V tolerant on I²C
  with internal pull-ups to 5 V works on this module) — no shifter
  needed. Other AS5600 boards may differ; check the breakout's pull-up
  voltage before assuming.

## Related

- [`BOM.md`](BOM.md) — procurement reference (suppliers, prices, qty).
- [`3d_printing.md`](3d_printing.md) — printing settings and the
  coin-pause technique for the pendulum link.
- [`sysid_runbook.md`](sysid_runbook.md) — measurement protocol that
  validates the electronics chain works end-to-end.

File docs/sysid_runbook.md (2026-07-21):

# System Identification Runbook

End-to-end protocol for measuring the physical parameters of your
pendulum and writing a `sysid_params.json` that the RL pipeline consumes.

Sysid runs against the **same** `LowLevelServer.ino` firmware the policy
deploys against — no firmware swap, no risk of measurement-vs-deployment
parameter drift.

The wizard is split into two phases:

- **collect** — operator-driven recording on the rig. Writes raw `.npz`
  logs + a `metadata.json` to a timestamped directory.
- **fit** — pure post-processing. Reads a directory of recordings, derives
  parameters, writes `sysid_params.json`, and renders sim-vs-real
  validation plots. No device required; re-runnable as often as you like.

Re-fitting from saved logs is the fast iteration loop when improving the
math. Re-collecting on the rig is only needed when changing sensor read
rates, firmware logic, or adding new recording steps.

## Prerequisites

- Python env: `mamba activate rotary-inverted-pendulum` with
  `numpy`, `scipy`, `pyserial`, `matplotlib`, `mujoco` installed.
- `LowLevelServer.ino` flashed onto the Arduino Nano. Auto-magnet-detect
  at boot; the firmware halts in `setup()` until it sees the pendulum
  magnet.
- A small rigid block (cardboard, foam, wood) to slide under the pendulum
  for the free-swing release.
- Pendulum geometry (mass, COM, inertia) comes from `urdf/model.urdf` —
  no operator-measured inputs are needed. If you've rebuilt or modified
  the pendulum, update Onshape → export → URDF first.

## Recommended path: full pipeline

```bash
cd RotaryInvertedPendulum-python/src/rl
python sysid_wizard.py
```

Walks you through, in order:

1. **Tare hanging position.** Pendulum hangs motionless; we sample for
   3 s and use the median as "physical hanging = 0" in the saved
   coordinate frame. Fixes the firmware-encoder-accumulator drift.
2. **Free-swing × 3.** Hold the motor arm firmly, slide the block under
   the pendulum to lift it (any reasonable angle — the sensor records the
   actual release angle), then slide the block out perpendicular to the
   swing plane. Recording is 10 s by default. Repeat three times.
3. **Motor ±90° sanity sweep.** Engages the motor and drives it through
   `0 → +90° → 0 → −90° → 0` using accel commands. Watch the rig: the
   arm should reach roughly perpendicular at the peaks. If it visibly
   under-shoots, the stepper is skipping steps and the firmware
   position-counter no longer matches the actual mechanical position
   — a deployment-blocker (lower `MOTOR_ACCELERATION` or bump the
   DRV8825 Vref).
4. **Fit + plots.** Aggregates the three free-swing recordings, derives
   friction parameters using URDF-defined geometry, writes
   `sysid_params.json`, generates `freeswing_compare.png` (sim trace
   overlaid on the real recording using the just-derived params) and
   `motor_sweep.png` (motor target vs. actual during the sanity sweep).

Pendulum mass, COM distance, and inertia about the COM are *not* part
of this pipeline anymore — they're geometric properties of the part and
live in `urdf/model.urdf`, parsed by `pendulum_geometry.py`. The free-
swing fit cross-checks the URDF inertia against the measured period
(a >10% mismatch flags a likely-stale URDF).

The whole thing takes ~10–15 minutes. Output ends up in
`sysid_runs/<timestamp>/` next to the wizard.

## Re-fit from existing recordings (no rig needed)

```bash
python sysid_wizard.py fit --in-dir sysid_runs/2026-05-20_090000
```

Use this when iterating on `sysid_core.derive_pendulum_friction` or
investigating the fits — the rig stays unused, and the operator doesn't
need to be present.

## Standalone motor sanity sweep

```bash
python sysid_wizard.py validate-motor
```

Just the motor ±90° sweep + plot. Useful after any change to the
firmware's motor configuration (current limit, microstepping,
acceleration ceiling) to confirm step counting still tracks reality.

## What the wizard writes

```
sysid_runs/2026-05-20_HHMMSS/
├── metadata.json               # port, firmware, timestamp, ...
├── tare.npz                    # pendulum-at-rest recording → hanging zero
├── free_run_1.npz              # raw free-swing recordings
├── free_run_2.npz
├── free_run_3.npz
├── motor_sweep.npz             # motor target/actual during sanity sweep
├── freeswing_compare.png       # sim-vs-real overlay for validation
└── motor_sweep.png             # motor target vs. firmware-reported position
```

`sysid_params.json` (the file the RL pipeline reads) is written at the
project root by default. It's gitignored — it's this specific rig's live
measurement (bearings, grease, and temperature all vary between physical
units, per CLAUDE.md), so it isn't shared across forks/rigs. If it's
missing, `pendulum_env.py` falls back to `sysid_profiles/aliexpress_uk.json`
(the reference values for the original kit) with a loud warning, since
silently running with someone else's friction numbers would just make
control subtly wrong rather than fail outright. Run this wizard to replace
that fallback with your own rig's measurement. If you want to keep a
snapshot of your own numbers as a named reference (e.g. to propose upstream
alongside a different kit's BOM), copy `sysid_params.json` into
`sysid_profiles/<name>.json` — that directory is version-controlled,
`sysid_params.json` itself is not.

## What the math does

`fit_free_swing(t, θ)` (in `sysid_core.py`) finds peaks, computes the
period and damped-oscillator decay constants. It also computes the
**small-amplitude period** T₀ via the elliptic-integral correction
`T(θ_max) = T₀ · (2/π) · K(sin²(θ_max/2))` — necessary because the
recordings are at finite amplitude (40–90°) but the inertia formula
`I = m·g·d·T²/(4π²)` is the small-amplitude one.

`derive_pendulum_friction(fit)` reads the pendulum geometry (mass, COM,
I_com) from `pendulum_geometry` (which parses `urdf/model.urdf`) and
combines it with the fit to produce viscous and Coulomb friction. It
also reports both `inertia_predicted_kg_m2` (CAD: m·d² + I_com) and
`inertia_measured_kg_m2` (from T₀: m·g·d/ω²), and `validate_free_swing`
warns if they disagree by more than 10% — a sign the URDF is stale or
the recording is contaminated.

Viscous friction uses the CAD-predicted pivot inertia: b = 2·α·I_pred,
where α = b/(2I) is the directly-measured envelope decay. Coulomb
friction comes from the Coulomb-step-per-half-cycle measured in the
envelope fit.

## Recovery and debugging

- **Free-swing fit fails** (too few extrema, no decay, etc.): the recording
  is bad — pendulum didn't move enough, or you released into a vibration
  source. Just retry that run when prompted.
- **Hanging zero drifted between recordings**: the firmware's accumulator
  is monotonic, so this happens if the operator manually wound the
  pendulum past ±180° between runs. Reset the firmware (USB disconnect
  + reconnect) and re-collect.
- **Re-fitting gives different numbers**: expected — small changes in
  the fitter compound. The `freeswing_compare.png` plot is the
  ground-truth: if real and sim envelopes overlap closely, the fit is
  correct regardless of the absolute values.

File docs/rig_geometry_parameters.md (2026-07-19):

# Rig Geometry Parameters

Physical geometry of this rig's two moving bodies (arm, pendulum), extracted
from `urdf/model.urdf` as plain numbers — no 3D model, no mesh files, no
ready-to-load robot description. If you're building your own simulation from
scratch, these are the numbers you need; the model itself (joint tree, mesh
geometry, loader code) is intentionally not provided here.

For per-rig dynamic parameters (motor response, friction) instead of static
geometry, see `sysid_params.json` and `sysid_runbook.md`.

## Convention

Each body's mass/COM/inertia is expressed in that body's own local frame,
with the origin at the joint that attaches it to its parent (standard URDF
convention: `inertial/origin` gives the COM position relative to the link
frame, `inertia` is the inertia tensor about the COM, axis-aligned with the
link frame).

## Bodies

### Arm (motor-driven link)

| Quantity | Value |
|---|---|
| Mass | 0.026 kg |
| COM position (link frame) | x=0.041 m, y=0 m, z=0.011 m |
| Inertia about COM, ixx | 4.29e-6 kg·m² |
| Inertia about COM, iyy | 1.756e-5 kg·m² |
| Inertia about COM, izz | 1.73e-5 kg·m² |
| Inertia about COM, ixz | -1.75e-6 kg·m² |
| Inertia about COM, ixy / iyz | 0 |

### Pendulum (free-swinging link)

| Quantity | Value |
|---|---|
| Mass | 0.014 kg |
| COM position (link frame) | x=0.062 m, y=0 m, z=-0.051 m |
| Inertia about COM, ixx | 8.06e-6 kg·m² |
| Inertia about COM, iyy | 8.55e-6 kg·m² |
| Inertia about COM, izz | 6.1e-7 kg·m² |
| Inertia about COM, iyz | 1.9e-7 kg·m² |
| Inertia about COM, ixy / ixz | 0 |

Note: the pendulum's swing axis is x. The x-component of its COM position is
therefore along the rotation axis and does not affect swing dynamics — only
the y/z components matter for the pendulum's effective moment arm.

## Joints

### base_to_arm (motor-actuated)

| Quantity | Value |
|---|---|
| Type | revolute, actuated |
| Origin offset from base | x=0, y=0, z=0.075 m |
| Origin rotation from base | rpy = 0, 0, -1.57079 rad |
| Rotation axis | z |

### arm_to_pendulum (free-swinging)

| Quantity | Value |
|---|---|
| Type | continuous, unactuated |
| Origin offset from arm | x=0, y=0, z=0.014 m |
| Origin rotation from arm | rpy = 0, 0, 0 |
| Rotation axis | x |

## Independent cross-check values

These come from physical measurements on this rig, independent of the CAD
numbers above — useful to sanity-check your own model once built:

- Measured pendulum free-swing period: ≈ 490 ms (10 half-swings in 2.45 s) →
  natural frequency ω_n ≈ 12.8 rad/s.
- Measured pendulum balance point: ≈ 51 mm from the pivot.
- Cross-check between measured period and CAD inertia: `m·g·d/ω²` gives
  I_axis ≈ 4.48e-5 kg·m², matching the CAD-derived `m·d² + I_com` (≈ 4.46e-5
  kg·m²) to within 1%.

## Not included here

- `urdf/model.urdf` itself (joint tree + mesh references, ready to load into
  a simulator).
- Mesh files (`meshes/*.dae`, `*.stl`) — visual/collision geometry, not
  needed for a physically-correct dynamics model.
- `pendulum_geometry.py` — the parser that extracts these numbers from the
  URDF at runtime.

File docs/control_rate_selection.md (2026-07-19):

# Choosing the Control Rate (and `max_action_delta_rad`)

Picking these is **not** a free choice. Done badly, the policy "works"
in sim and is broken on hardware, or vice versa. Done correctly, the
choice falls out of the sysid measurements.

This doc covers the *how* (numerical recipe) and the *why* (physical
constraints). For *what one transition looks like* once these are
fixed, see [`rl_transitions.md`](rl_transitions.md). For *how* the chosen
rate is enforced at runtime, see [`async_control_architecture.md`](async_control_architecture.md).

## Knob taxonomy: auto-derived vs user-set

The RL pipeline has many tunable parameters. They split cleanly into two
categories, and that split is enforced in the code:

**Auto-derived from other inputs** (you don't set these directly):

| Knob | Derived from | Why auto |
|---|---|---|
| `vel_filter_cutoff_hz` | `control_freq_hz` | Pure hygiene — keep filter below Nyquist + above signal bw. No design choice involved. |
| Curriculum DR delay ranges (steps) | `control_freq_hz` × physical-ms ranges | Physical delay (ms) is the meaningful unit; step count is just bookkeeping. |
| `n_substeps` (sim) | `control_freq_hz` / physics_dt | MuJoCo bookkeeping, no design content. |

**User-set** (you decide these explicitly):

| Knob | What it encodes | Why explicit |
|---|---|---|
| `control_freq_hz` | The rate window choice from sysid | Design decision: where in `[5×f_n, 3×BW_motor]` to land |
| `max_action_delta_rad` | Slew budget per tick | Design decision: how reactive should the policy be? |
| `dt_jitter_frac` (per stage) | DR strength on timing | Curriculum decision: how aggressive should regularization be? |
| `k_action`, `k_θ`, `k_motor_pos`, etc. | Policy-shaping weights | Design decision: what behavior does the reward favor? |
| Stage delay ranges (in ms, before scaling) | DR width per stage | Curriculum decision: how hard is each stage? |

**Rule**: auto-derive when there's an obvious right answer that follows
mechanically from another input. Stay explicit when the choice encodes
*intent* about how the policy should behave. Auto-derivation is hygiene;
user-set knobs are design.

This split means:
- New users on this rig don't need to remember the filter formula —
  pick a control rate and the rest of the hygiene works out.
- Override paths exist for every auto-derived knob (just pass an
  explicit value), so no magic prevents experimentation.
- The user-set knobs are the actual design surface — the small set of
  numbers where you have to think.

## Inputs (from sysid)

Two physical numbers, both produced by Phase 0 sysid:

| Quantity | How it's measured | This rig's value |
|---|---|---|
| **Motor bandwidth** `BW_motor` | `1 / (2π × rise_time_95)` from step response | **16 Hz** (64 ms rise) |
| **Pendulum natural frequency** `f_n` | `1 / period_s` from free-swing fit | **1.9 Hz** (0.526 s period) |

Both live in `sysid_params.json` after the runbook protocol. Re-derive
them whenever the rig changes (new bearings, motor swap, etc.). See
[`sysid_runbook.md`](sysid_runbook.md) for the measurement procedure.

## The valid control-rate window

The sample rate has to satisfy *both* of these inequalities simultaneously:

1. **Lower bound — pendulum-driven**: sample fast enough to control the
   unstable upright mode. Rule: `f_ctrl ≥ 5–10 × f_n`. For this rig,
   that's ≥ 10–20 Hz minimum.
2. **Upper bound — motor-driven**: don't sample faster than the motor
   can physically respond. Rule: `f_ctrl ≤ 2–3 × BW_motor`. For this
   rig, that's ≤ 32–50 Hz.

Yours: **window is roughly 30–50 Hz.** Outside it:

- Below 30 Hz: pendulum can swing significantly between ticks; closed-
  loop control becomes underdamped or unstable.
- Above 50 Hz: motor low-passes incoming targets; the policy fights
  against its own un-tracked past commands. Empirically observed: at
  100 Hz training-and-deployment, our policy's deployed avg upright
  proxy was 0.69. At 35 Hz: 0.89. Same model architecture; same hardware.
  The mismatch alone explained the gap.

## Slew rate — the per-second budget

The *slew rate* is how fast the policy is allowed to change its motor
target, measured in rad/s. It's the product of two knobs:

```
slew = max_action_delta_rad × control_freq_hz   (rad/s)
```

**What it means intuitively**: if your policy outputs the maximum action
(`a = +1.0`) every tick for one second, this is how far the motor target
moves in that second. It's the maximum demand the policy can place on
the actuator over one second of sustained extreme commands.

**Sane bound**: `slew ≤ BW_motor × A_max`, where `A_max ≈ 0.2 rad` is
the largest single setpoint step a stepper can usefully execute without
the trapezoidal profile dominating. For this rig:

`slew ≤ 16 Hz × 0.2 rad = 3.2 rad/s` (conservative)

Up to ~5 rad/s is fine in practice (motor-bandwidth headroom and the
1st-order lag don't fall off cliff-edge-suddenly).

## How it composes — this rig's numbers

| Setup | rate | delta | slew | In window? | Empirical result |
|---|---|---|---|---|---|
| Sim default (Phase 1) | 100 Hz | 0.10 | 10 rad/s | rate too high, slew too high | 0.69 upright; chattery, motor fights itself |
| 50 Hz | 50 Hz | 0.10 | 5.0 rad/s | rate at upper edge | 0.74 upright; "active correction" attractor |
| 40 Hz | 40 Hz | 0.10 | 4.0 rad/s | within window | 0.72 upright; same active attractor |
| **35 Hz** | **35 Hz** | **0.10** | **3.5 rad/s** | **calm-attractor side** | **0.91 upright; "minimal action" attractor — motor barely moves when balanced** |

## The two attractors — empirical observation

SAC reliably converges to one of two qualitatively different policies on
this rig, depending on the slew budget:

- **Calm attractor (slew ≤ ~3.5 rad/s)**: motor commands stay within
  ±0.05 rad even at full balance. Per-step action cost approaches zero.
  Visually: pendulum is statue-still, motor is essentially at rest.
  Robust against bearing noise; the policy sees the rig as
  "self-stable enough" near upright.
- **Active-correction attractor (slew ≥ ~4.0 rad/s)**: motor commands
  routinely swing ±0.5 rad even when balanced. Per-step *theta* cost
  is fine (the policy keeps θ near zero), but per-step *action* cost
  is high. Visually: pendulum jitters as motor saws back and forth.

The boundary between them is sharp — **between 35 and 40 Hz on this
rig**, with `max_action_delta_rad=0.10`. Confirmed by training a 40 Hz
policy starting from the calm 35 Hz checkpoint: 50 episodes of
fine-tuning at the higher rate flipped it into the active attractor.

The reward weights (`k_action=0.05`, `k_θ=1.0`) under-penalize action
effort relative to θ deviation. SAC will choose active correction
whenever it has the slew budget for it; the only thing keeping the 35 Hz
policy in the calm attractor is that 3.5 rad/s isn't *enough* slew for
active correction to actually beat passive stabilization in reward.

## Recipe for picking rate + delta on a new rig

## Recipe for picking rate + delta on a new rig

1. Run sysid (see [`sysid_runbook.md`](sysid_runbook.md)). Note `BW_motor`
   and `f_n`.
2. Compute the rate window: `[5 × f_n, 3 × BW_motor]`. If empty, you
   need a faster motor before this rig is controllable.
3. Pick a rate in the window. **Bias toward the lower edge.**
   Empirically (see the attractor analysis above), SAC tends to land in
   a "calm" minimal-action attractor when slew is at or below
   `BW_motor × 0.2`, and a "twitchy" active-correction attractor above
   that. Lower-edge rates also have margin against motor-BW variation
   under load. The naive "higher = more reactive" intuition fails here
   because the policy's reactivity comes from its action distribution,
   not its decision rate — and the active attractor produces *less*
   useful reactivity (just self-fighting).
4. Pick `max_action_delta_rad` so `delta × rate ≤ BW_motor × 0.2 ≈
   ~3.2-3.5 rad/s` (stays in the calm attractor on this rig).
5. Configure `control_freq_hz` and `max_action_delta_rad` consistently
   across **sim training**, **fine-tuning**, **and deployment**. The
   policy learns the rate it was trained at; mismatched deployment
   was the bug we built `async_control.py` to prevent — see
   [`async_control_architecture.md`](async_control_architecture.md).

## Sequence summary

```
sysid → BW_motor + f_n
      → rate window [5·f_n, 3·BW_motor]
      → pick f_ctrl in window (lower = conservative, higher = reactive)
      → pick max_action_delta_rad such that delta × f_ctrl ≤ ~3.5 rad/s
      → set those values once; use everywhere (sim, fine-tune, deploy)
```

## Velocity filter cutoff — picking it from the rate

The observation pipeline finite-differences raw encoder positions and
runs the result through a 1st-order low-pass IIR filter. Cutoff
frequency `vel_filter_cutoff_hz` should be picked relative to the
chosen control rate, not absolutely. If you change `control_freq_hz`,
re-derive the cutoff.

### The bound

Two inequalities, similar in spirit to the control-rate window:

1. **Lower bound — preserve the signal.** Cutoff must sit *above* the
   highest meaningful frequency in your closed-loop dynamics. For an
   inverted pendulum that's the upright instability time constant
   `1/τ = ω_n ≈ 12 Hz` for this rig. Below ~12 Hz cutoff, the filter
   attenuates the very signal the policy needs to react to.
2. **Upper bound — Nyquist.** A 1st-order filter's roll-off is gentle.
   Cutoff at or above `0.5 × control_freq_hz` (Nyquist) means each new
   sample contributes ≥75% to the running estimate — the filter is
   essentially a passthrough and isn't doing useful smoothing.

The sweet spot: **cutoff between the highest signal frequency and
~half of Nyquist**.

### This rig's numbers

Pendulum's upright-instability mode at ~12 Hz, so cutoff ≥ ~10 Hz to
preserve signal. Nyquist at the chosen rate dictates the upper bound.
The encoder noise spectrum peters out somewhere around ~20 Hz, so a
cap there avoids near-passthrough at high control rates.

### Auto-derivation (current default)

Both `real_env.py` and `run_policy.py` auto-derive the cutoff from
`control_freq_hz` if you don't pass `--vel-filter-cutoff-hz`:

```
cutoff = min(20.0, max(10.0, 0.4 × control_freq_hz))
```

| Control rate | Auto cutoff | Why |
|---|---|---|
| ≥ 50 Hz | 20.0 (capped) | Above this we'd be near-passthrough; capping at 20 keeps real filtering for noise |
| 40 Hz | 16.0 | 40% of rate, ~80% of Nyquist |
| 35 Hz | 14.0 | 40% of rate |
| **30 Hz** | **12.0** | 40% of rate, just above the 12 Hz signal edge |
| ≤ 25 Hz | 10.0 (floor) | Floor protects signal preservation; below this the filter starts attenuating useful pendulum dynamics |

The 0.4 multiplier gives ~80% of Nyquist when uncapped — solidly
filtering, not passthrough. The 10/20 Hz clamps reflect *this rig's*
signal bandwidth (~12 Hz) and noise spectrum (~20 Hz). On a different
rig these would shift with the new sysid.

### When to override

`--vel-filter-cutoff-hz N` forces a specific value. Reasons to override:

- **You see noisy actions in deployment**: cutoff might be too high.
  Drop ~2-3 Hz below the auto value.
- **You see sluggish reaction to disturbances**: cutoff too low.
  Raise ~2-3 Hz above auto.
- **You're swapping the pendulum / motor**: re-derive the rig's signal
  bandwidth and noise spectrum from sysid; pick new clamp values
  before relying on auto.

### When to retune

Change the cutoff if any of:

- **Control rate changes substantially** (more than ~2×): Nyquist
  shifts; pick a new cutoff in the new sweet spot.
- **Rig dynamics change** (different pendulum, different motor): the
  upright instability frequency shifts. Re-measure via sysid; recompute
  the lower bound.
- **You see noisy actions in deployment**: cutoff too high, dropping
  cutoff to ~12 Hz adds smoothing.
- **You see sluggish reaction to disturbances**: cutoff too low,
  attenuating useful signal. Bump up to 18-20 Hz.

## Where the chosen values live in code

| Knob | Default | Where it's set / read |
|---|---|---|
| `control_freq_hz` | **35** everywhere — `pendulum_env.py`, `real_env.py`, `async_control.py`, and `--control-freq` defaults in `train_sac.py` / `finetune_async.py` / `eval_randomized.py` / `run_policy.py` / `distill.py`. The historic 100 Hz default predated the empirical 35 Hz finding (Phase 4.6) and was wrong for this rig. | Sim env `__init__`, real env `__init__`, deployment loop |
| `max_action_delta_rad` | 0.10 in env `__init__`; `--max-action-delta-rad` flag in `train_sac.py` and `finetune_async.py` | Inside `step()` / `apply_action()` clipping |
| Curriculum stage delays (steps) | Computed in `curriculum_train.sh` from physical milliseconds × `CONTROL_FREQ` | Bash arithmetic at script top |

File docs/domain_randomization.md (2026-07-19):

# Domain Randomization (sim training)

Sim-to-real for this rig is a closed-loop instability problem on a
position-controlled stepper. Anything we miss in the sim model the
policy will silently overfit to. Domain randomization (DR) is the
mechanism we use to bridge that gap: we train against a *distribution*
of plausible rigs rather than a single nominal one, so the policy is
robust to the residual mismatch between our identified parameters and
whatever the real hardware looks like on a given day.

This doc summarises **what is randomized, by how much, and why**, plus
how DR fits into the curriculum schedule and where the knobs live in
code. For the broader RL plan (phases, decisions, status) see
[`../RL_PLAN.md`](../RL_PLAN.md). For the transition-level contract see
[`rl_transitions.md`](rl_transitions.md). For the sysid measurements
that set the bracketed values see [`sysid_runbook.md`](sysid_runbook.md).

## How to enable it

```bash
python train_sac.py --domain-randomization ...
```

Or, equivalently, run the full curriculum:

```bash
./curriculum_train.sh <run-name-prefix>
```

The flag flips a single boolean on the env
([`pendulum_env.py:248`](../RotaryInvertedPendulum-python/src/rl/pendulum_env.py#L248)).
When off, the env runs deterministically against the nominal
sysid params — useful for debugging but **never** for the policy that
will be deployed.

The **eval env always stays deterministic** (DR off), so best-model
selection during training tracks performance on the nominal-physics
reference scenario instead of being washed out by sample-to-sample
randomisation noise. See
[`train_sac.py:86`](../RotaryInvertedPendulum-python/src/rl/train_sac.py#L86).

## What is randomized

All ranges are defined as module constants in
[`pendulum_env.py:61-97`](../RotaryInvertedPendulum-python/src/rl/pendulum_env.py#L61-L97).
Most are sampled **once per episode** in
[`_sample_dr_params`](../RotaryInvertedPendulum-python/src/rl/pendulum_env.py#L384);
the dt-jitter and observation noise are sampled **per step**.

### Physical parameters (per episode)

| Parameter | Range | Source constant | Why this width |
| --- | --- | --- | --- |
| Pendulum mass | nominal × (1 ± 0.10) | `DR_PENDULUM_MASS_FRAC = 0.10` | Narrowed from ±0.20 after CAD cross-check (Onshape part with PLA-density-corrected materials) agreed with sysid `m·d` to within 1%; mass is a one-shot scale measurement and the remaining uncertainty (unmodelled magnet, infill variation) sits well inside ±10%. |
| Pendulum COM distance | nominal × (1 ± 0.10) | `DR_PENDULUM_COM_FRAC = 0.10` | Bearing seating and tip mass placement vary; ±10 % covers reasonable rebuilds. |
| Pendulum joint friction (viscous + Coulomb) | nominal × [0.5, 2.0] | `DR_PENDULUM_FRICTION_MULT_RANGE = (0.5, 2.0)` | Friction depends on grease state, temperature, and bearing seating; same multiplier applied to both terms because they share the bearing as a source. |
| Motor joint stiction (`frictionloss`) | [0.0, 0.005] N·m | `DR_MOTOR_FRICTIONLOSS_RANGE_N_M = (0.0, 0.005)` | Steppers have detent torque that the position actuator doesn't capture; lower bound includes 0 for backward compat with Phase 2 policies trained without stiction. |

Nominal values come from
[`sysid_params.json`](../RotaryInvertedPendulum-python/src/rl/sysid_params.json),
written by the Phase 0 sysid pipeline. **Pendulum inertia about its own
COM** (`PENDULUM_I_COM_SWING_KG_M2` at
[`pendulum_env.py:71`](../RotaryInvertedPendulum-python/src/rl/pendulum_env.py#L71))
is hard-coded from Onshape CAD rather than back-computed from sysid
`I_axis − m·d²` — it's a geometric property of the part, not a quantity
that varies with rebuilds, so it isn't randomised. MuJoCo applies
parallel-axis automatically from `body_ipos`, giving per-episode pivot
inertia `m·d² + I_com_swing`. Previously this was forced to ≈0 (point-
mass approximation); the CAD value (~8.06e-6 kg·m²) adds ~25% to the
effective pivot inertia at nominal, matching the measured `I_axis`.

### Actuator / control-loop realism (per episode)

| Parameter | Range | Source constant | Why this width |
| --- | --- | --- | --- |
| Motor first-order lag τ | [0.0, 0.010] s | `DR_MOTOR_TAU_RANGE_S` | Phase 2.5 fits against real-hardware logs found τ ≈ 0; we still sweep up to 10 ms to keep a robustness margin against load-dependent slowdowns. |
| Action delay (transport delay on commands) | [4, 7] control steps | `DR_ACTION_DELAY_STEPS_RANGE` | At 100 Hz, brackets the measured ~50 ms hardware delay (5 steps) ±1 step margin. Phase 2.6 widened this after lowering `MOTOR_ACCELERATION` (100 k → 50 k steps/s²) on the Arduino. The curriculum scales this to physical ms at lower control rates — see below. |
| Control-step dt jitter | n_substeps × (1 ± 0.05) per step | `DR_CONTROL_DT_JITTER_FRAC = 0.05` | Empirically the single most important DR. Without it, SAC at strict timing finds the **active-correction attractor** (motor saws ±0.5 rad even when balanced); with it, SAC finds the **calm minimal-action attractor** that dominates real-world performance. See [`control_rate_selection.md`](control_rate_selection.md) "calm vs active attractors". |

### Observation noise (per step)

| Parameter | Range | Source constant | Why this width |
| --- | --- | --- | --- |
| Pendulum angle quantisation | snapped to AS5600 LSB (2π / 4096 rad) | `PENDULUM_LSB_RAD` | Models the encoder's 12-bit resolution. Always applied when DR is on. |
| Position noise σ | 0.005 rad | `DR_OBS_NOISE_STD_POS_RAD` | Mimics finite-diff jitter and encoder noise observed on the rig. Added to motor pos and pendulum angle. |
| Velocity noise σ | 0.05 rad/s | `DR_OBS_NOISE_STD_VEL_RAD_S` | Velocity is finite-differenced from a noisy position signal; σ chosen to match the observed jitter at this rig's filter cutoff. |

## Curriculum staging

Training in three stages
([`curriculum_train.sh`](../RotaryInvertedPendulum-python/src/rl/curriculum_train.sh))
is more reliable than one shot at full DR width. Each stage `--resume`s
from the last so capabilities accumulate.

The two parameters that are annealed across stages are **action delay**
and **dt jitter**. The other DR ranges are constant for all stages
because the policy benefits from seeing them from the start.

| Stage | Action delay (physical) | Motor τ | dt jitter | Steps |
| --- | --- | --- | --- | --- |
| **1 — easy** | [0, 20] ms | [0, 5] ms  | ±20 % | `STEPS_PER_STAGE` |
| **2 — medium** | [20, 50] ms | [0, 10] ms | ±10 % | `STEPS_PER_STAGE` |
| **3 — final**  | [30, 60] ms | [0, 10] ms | ±5 % | `STEPS_PER_STAGE` |

Notes:

- The script converts physical-ms ranges into integer step counts at the
  configured `CONTROL_FREQ`. At low rates (e.g. 35 Hz) stages 2 and 3
  can collide after rounding; in that case stage 3 is skipped and the
  final policy is the stage-2 best model. The script logs this clearly.
- The dt-jitter anneal is intentional: high jitter early forces the
  policy out of the active-correction attractor; lower jitter later
  lets it specialise for deployment-realistic timing.
- Stage 3 brackets the hardware's ~50 ms delay with ~one step of margin
  on each side at 35 Hz (the canonical rate for this rig).

## Reset diversity (not strictly DR, but adjacent)

`reset()` itself adds initial-condition diversity that is essential for
the policy to learn recovery from arbitrary starts:

- **Motor start**: uniform in ±0.7 × motor safety limit (≈ ±88°). Keeps
  the reset clear of the ±125° clamp while covering most of the working
  range. Without this, the policy never practises returning from the
  limit and gets stuck there at deploy time
  ([`pendulum_env.py:362-374`](../RotaryInvertedPendulum-python/src/rl/pendulum_env.py#L362-L374)).
- **Pendulum start**: hanging-down ± 0.05 rad (small noise around the
  natural rest angle).

This is on regardless of `--domain-randomization` because it's about
training-state coverage, not modelling-error robustness.

## Where the knobs live

| Knob | Default | Where it's set / read |
| --- | --- | --- |
| Module constants (`DR_*`) | as above | [`pendulum_env.py:61-97`](../RotaryInvertedPendulum-python/src/rl/pendulum_env.py#L61-L97) |
| Per-instance overrides (curriculum) | None → fall back to module constants | `RotaryInvertedPendulumEnv.__init__` ([`pendulum_env.py:255-284`](../RotaryInvertedPendulum-python/src/rl/pendulum_env.py#L255-L284)) |
| CLI overrides | unset → module defaults | `train_sac.py` flags `--dr-tau-min/max`, `--dr-delay-min/max`, `--dr-dt-jitter-frac` ([`train_sac.py:198-226`](../RotaryInvertedPendulum-python/src/rl/train_sac.py#L198-L226)) |
| Curriculum stage values | hard-coded ms targets | [`curriculum_train.sh`](../RotaryInvertedPendulum-python/src/rl/curriculum_train.sh) |

## Editing the ranges

When real hardware tells you something the sim missed:

1. **Re-run sysid first.** If the nominal parameters drifted (new
   bearings, motor swap, etc.), update those before widening DR — DR
   doesn't replace good identification, it just brackets its residuals.
   See [`sysid_runbook.md`](sysid_runbook.md).
2. **Widen the matching DR range** in `pendulum_env.py`. Keep ranges
   conservative — they should bracket measured reality with margin, not
   include physically implausible regimes (those just slow training and
   teach the policy nothing useful).
3. **Re-train from scratch through the full curriculum.** Resume from
   stage-3 checkpoints is unsafe when the underlying distribution
   shifts; stage-1 will adapt the basics fastest.
4. **Validate with `eval_randomized.py`** to spot-check the policy's
   robustness across the new range before deploying.

## Related

- [`control_rate_selection.md`](control_rate_selection.md) — why dt
  jitter is the load-bearing DR knob on this rig.
- [`rl_transitions.md`](rl_transitions.md) — the `(s, a, r, s')`
  contract DR perturbs.
- [`sysid_runbook.md`](sysid_runbook.md) — measurement procedure for
  the nominal values DR brackets.
- [`async_control_architecture.md`](async_control_architecture.md) —
  how the deployment runtime preserves the timing assumptions DR
  trained against.

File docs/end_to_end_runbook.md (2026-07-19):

# End-to-End Runbook

How to take a freshly-built rig from "no policy at all" to "balances
standalone on the Nano, no laptop tether". Each step lists the command,
the expected wall-clock cost, and what the next step depends on.

For *why* the pipeline is shaped this way, see [`../RL_PLAN.md`](../RL_PLAN.md).
For *how a single transition works*, see [`rl_transitions.md`](rl_transitions.md).

```
   ┌──────────┐    ┌──────────┐    ┌──────────────┐    ┌──────────────┐
   │ 0 sysid  │───▶│ 1 sim    │───▶│ 2 fine-tune  │───▶│ 3 test       │
   │  recordings    curriculum     real-rig async      teacher tethered
   └──────────┘    └──────────┘    └──────────────┘    └──────┬───────┘
                                                              │ scored ≥ 0.9?
                                                              ▼
                                  ┌──────────────────────┐    ┌──────────┐
                                  │ 6 flash + verify     │◀───│ 4 distill│
                                  │ on-device standalone │    │ student  │
                                  └──────────────────────┘    └────┬─────┘
                                                                   │
                                                              ┌────▼──────┐
                                                              │ 5 test    │
                                                              │ student   │
                                                              │ tethered  │
                                                              └───────────┘
```

If you only need the upright/balance behaviour and are happy keeping the
laptop attached: stop after step 3. Steps 4–6 only exist to remove the
tether.

## Prerequisites

- macOS / Linux dev box with `arduino-cli`, the `arduino:avr` core, and
  the `AS5600` (RobTillaart) + `FastAccelStepper` libraries installed.
- Python env per [`../RotaryInvertedPendulum-python/README.md`](../RotaryInvertedPendulum-python/README.md):
  `mamba activate rotary-inverted-pendulum`.
- Rig wired with **STEP on pin 9**, DIR on pin 2, ENABLE on pin 5, AS5600
  on I²C (A4/A5). Pin 9 is required by FastAccelStepper on ATmega328 and
  works for AccelStepper too — see
  [`../NEXT_STEPS.md`](../NEXT_STEPS.md).

In the commands below, replace `/dev/cu.usbserial-1130` with whatever
port `arduino-cli board list` shows for your Nano.

## 0. System identification — measure the rig

Pinning the dynamics parameters once. Outputs `sysid_params.json`,
which `pendulum_env.py` reads to build the sim.

Full protocol: [`sysid_runbook.md`](sysid_runbook.md). Re-run any time
the rig changes mechanically (new bearings, rebuilt arm, changed
microstepping, swapped motor).

## 1. Train the teacher in sim — curriculum

The repo's canonical recipe trains a SAC actor through three DR stages
of increasing realism. End-to-end ~25 min on the MacBook (CPU, single
env). Outputs `runs/<run-name>/last.zip`.

```bash
cd RotaryInvertedPendulum-python/src/rl
bash curriculum_train.sh
```

`curriculum_train.sh` reads `sysid_params.json`, derives DR ranges from
physical-time-units, runs three stages, and writes the final policy
plus checkpoints. The `control_freq_hz` is **35 Hz** by default in
every component — see [`control_rate_selection.md`](control_rate_selection.md)
for why.

## 2. Fine-tune on the real rig — async

The sim policy will not balance on hardware on its first try
(sim-to-real gap). Async fine-tuning closes that gap with ~30–80
real-rig episodes (~10–25 min wall clock).

Flash the LowLevelServer first so the laptop can drive the rig over the
binary protocol:

```bash
arduino-cli compile --upload -p /dev/cu.usbserial-1130 \
    --fqbn arduino:avr:nano:cpu=atmega328 \
    RotaryInvertedPendulum-arduino/LowLevelServer
```

Then run the async orchestrator. `--resume-buffer` is optional on the
first session; on subsequent sessions, point it at the previous run's
`replay_buffer.pkl` to keep accumulated real-rig transitions:

```bash
cd RotaryInvertedPendulum-python/src/rl

# First fine-tune session
python finetune_async.py \
    --policy runs/<sim-run>/last.zip \
    --port /dev/cu.usbserial-1130 \
    --episodes 50 \
    --run-name async_v1

# Subsequent sessions, buffer-resumed
python finetune_async.py \
    --policy runs/async_v1/last.zip \
    --resume-buffer runs/async_v1/replay_buffer.pkl \
    --port /dev/cu.usbserial-1130 \
    --episodes 30 \
    --run-name async_v1_extend
```

Architecture detail: [`async_control_architecture.md`](async_control_architecture.md).

The orchestrator disengages the motor for `--reset-settle-s` (default 5)
between episodes so the pendulum coasts to rest passively. **Listen** to
the motor during the first few episodes — a smooth whirr is fine, a
buzzy/grinding sound means step-skipping (drop `MOTOR_ACCELERATION` in
`LowLevelServer.ino` and `RLControl.ino` from 50 k → 30 k and re-flash).

## 3. Test the teacher on the rig — tethered

Confirms the fine-tuned teacher actually balances before spending more
time on it. Cheap (30 seconds of rig time).

```bash
python run_policy.py \
    --policy runs/async_v1_extend/last.zip \
    --port /dev/cu.usbserial-1130 \
    --duration-s 30
```

Watch the printed `upright` proxy at the end:
- **mean ≥ 0.9** → solid teacher, proceed to step 4 to remove the tether.
- **mean 0.85–0.9** → acceptable; can proceed but a few more fine-tune
  episodes (back to step 2 with `--resume-buffer`) usually buys
  robustness.
- **mean < 0.85** → fine-tuning didn't converge. Diagnose before
  distilling: check the
  [policy improvement ideas](policy_improvement_ideas.md) backlog,
  consider re-sysid, consider a wider `--gradient-steps`.

If you're happy keeping the laptop attached, **you can stop here**.
The teacher runs at 35 Hz over USB serial just fine.

## 4. Distill — shrink the actor for the Nano

The fine-tuned SAC actor is 67 K parameters (≈ 270 KB float32) — far
too big for the Nano's 32 KB flash. Distill into a 5→32→32→1 student
(≈ 5 KB). Cheap (~1 minute):

```bash
python distill.py \
    --teacher runs/async_v1_extend/last.zip \
    --buffer  runs/async_v1_extend/replay_buffer.pkl \
    --out-dir runs/async_v1_extend/distill_h32_aug
```

`distill.py`:
1. Loads teacher + replay buffer (real-rig observations).
2. Re-evaluates the deterministic-mean teacher action on each obs.
3. Augments with 100 K teacher rollouts in the DR sim (helps when
   the real-rig buffer is small/sparse).
4. Trains a tiny MLP via supervised regression with a tanh head.
5. Sanity-checks numpy parity with PyTorch (catches export bugs).

Acceptance for the student: validation MSE ≲ 0.02 in action units, plus
the tethered rollout in the next step. Closed-loop sim eval was removed
from `distill.py` because it isn't a meaningful gate for real-rig
fine-tuned teachers — they routinely fail the sim eval even when they
balance perfectly on hardware.

## 5. Test the student on the rig — tethered

Confirms the student is a faithful distillation of the teacher *before*
flashing it onto the Nano. Same `run_policy.py` flow but with the `.pt`
file. Cheap (30 s of rig time):

```bash
python run_policy.py \
    --policy runs/async_v1_extend/distill_h32_aug/student.pt \
    --port /dev/cu.usbserial-1130 \
    --duration-s 30
```

Expect the upright proxy to be **within ~0.05** of the teacher's score
from step 3. Larger gap → covariate-shift problem; either grow the sim
augmentation (`distill.py --sim-augment-steps 200000`), increase student
capacity (H=48 still fits comfortably), or accept and move on.

## 6. Flash the standalone sketch — remove the tether

```bash
# Export PROGMEM weights into the Arduino sketch directory
python export_weights.py \
    --student runs/async_v1_extend/distill_h32_aug/student.pt \
    --header  ../../../RotaryInvertedPendulum-arduino/RLControl/policy_weights.h \
    --source-name async_v1_extend/distill_h32_aug

# (Optional but recommended) update the boot self-test reference values
# in RLControl.ino to match the new student. Compute via:
#   python -c "import torch, numpy as np; from distill import StudentMLP, _student_predict_factory; \
#       ckpt = torch.load('runs/async_v1_extend/distill_h32_aug/student.pt', \
#           map_location='cpu', weights_only=True); \
#       m = StudentMLP(hidden=ckpt['hidden'], obs_dim=ckpt['obs_dim'], act_dim=ckpt['act_dim']); \
#       m.load_state_dict(ckpt['state_dict']); pred = _student_predict_factory(m); \
#       print('hanging:', float(pred(np.array([0,0,-1,0,0],dtype=np.float32))[0])); \
#       print('upright:', float(pred(np.array([0,0,1,0,0],dtype=np.float32))[0]))"

# Flash
cd ../../..
arduino-cli compile --upload -p /dev/cu.usbserial-1130 \
    --fqbn arduino:avr:nano:cpu=atmega328 \
    RotaryInvertedPendulum-arduino/RLControl
```

Pin the pendulum hanging straight down at the moment the **3 s startup
delay** ends (when the LED switches from slow blink to fast blink) —
that pose becomes the encoder zero for the engagement.

Verify on serial monitor at 500 kbaud:
- Boot prints `[boot] policy(hanging) = X.XXXX` and
  `[boot] policy(upright) = X.XXXX`. These should match the values you
  computed in the helper one-liner above to ≤ 1e-3 (AVR float vs
  PyTorch). If they don't, the C++ forward pass / PROGMEM access is
  broken — re-export, recompile, re-flash.
- Once engaged: pendulum should swing up and balance within ~3 s, hold
  ≥ 30 s undisturbed, recover from a flick disturbance.

## Re-running individual steps

Every step is idempotent and can be re-run on its own:

| Want to | Re-run | Resume from |
|---|---|---|
| Tweak rewards or DR ranges | step 1 | scratch |
| Add real-rig data | step 2 | `--resume-buffer` |
| Try a smaller / larger student | step 4 | existing teacher |
| Re-flash with the same student | step 6 | existing `.h` |

## Troubleshooting

- **Teacher balances tethered but student fails on Nano**: the most
  likely bug is the encoder zero — captured *at engage time* in
  `RLControl.ino`, but if the sketch was uploaded with the pendulum in
  a non-hanging pose and not re-positioned during the 3 s delay, the
  policy frame is rotated. Reset the Arduino with the pendulum hanging.
- **Boot self-test prints `[FATAL] FastAccelStepper config rejected`**:
  the requested `MOTOR_MAX_SPEED` exceeds FastAccelStepper's AVR cap of
  50 kSteps/s for a single stepper. Check the constant in
  `RLControl.ino`.
- **Pendulum swings but never reaches upright**: motor authority is
  too low. Verify the `MOTOR_ACCELERATION` matches between
  `LowLevelServer.ino` (used during fine-tuning) and `RLControl.ino`
  (used at deployment). They must agree, otherwise the policy is
  trained against one set of dynamics and deployed against another.

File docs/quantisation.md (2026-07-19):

# On-device weight quantisation

Notes on quantising the distilled student MLP for the Arduino Nano. The
broader rationale (when to bother, end-to-end recipe, code-change scope)
is in [`policy_improvement_ideas.md`](policy_improvement_ideas.md) under
"On-device performance"; this file captures the **format choice** and
the techniques that actually got int8 to work.

The Arduino Nano runs an **AVR** ATmega328P. AVR is the family of 8-bit
RISC microcontrollers originally designed by Alf-Egil Bogen and Vegard
Wollan (hence "AVR" — *Alf and Vegard's RISC*) and currently sold by
Microchip Technology after the Atmel acquisition. AVR has no FPU, so
the choice of weight format is dominated by which integer multiplications
the silicon can do natively.

## int8 vs int16 on AVR

Speed and fidelity numbers:

| Format | Bytes/weight | Per-MAC cost | Quantisation granularity | Forward pass (1216 MAC) |
|---|---|---|---|---|
| float32 | 4 | ~190 cycles (MUL + ADD, software) | ~7 decimal digits | ~14.5 ms |
| **int8** | **1** | **~5 cycles** (1× MUL + acc) | **max(W) / 127** | **~0.4 ms (~36× faster)** |
| int16 | 2 | ~15 cycles (4× MUL + accumulate) | max(W) / 32767 (~256× finer than int8) | ~1.1 ms (~13× faster) |

AVR has hardware `MUL` (8×8→16) and `MULS` (signed 8×8) but **no 16×16
multiplier** — int16 multiplication is composed from four 8×8 MULs plus
carries. So int16 is 3× slower per MAC than int8 even though the number
of bytes only doubles.

## Decision

**Use int8.** The hardware path is direct (a single `MULS` instruction
per weight×activation product, two cycles), and the resulting 36×
speedup over float32 is the whole reason to do quantisation in the first
place. Quantisation-aware training (QAT) plus the techniques below
closes the fidelity gap to negligible — this is the same recipe the
embedded-NN ecosystem (TFLite Micro, ONNX Runtime Mobile, MobileNet
papers) standardises on.

**int16 is the fallback** if int8 ever can't be made to hit the
closed-loop balance behaviour of the float student. int16 with even
post-training quantisation is essentially fidelity-equivalent to float
(256× finer granularity than int8), so it's the safety net — but at
3× the per-MAC cost, it shouldn't be the default.

## What it took to make int8 actually work on this rig

A naive int8 + QAT pipeline (per-tensor scaling everywhere, weights and
activations both in int8 range, no special handling of biases or input
heterogeneity) gets stuck at **~0.70 mean upright** on this rig — the
policy *catches* the pendulum reliably but can't *hold* it, drifting
out of the calm attractor within a few seconds. Closing that gap to
0.951 required layering several techniques on top of vanilla QAT. None
are exotic; they're all canonical "make int8 work" tricks.

### 1. Quantisation-aware training (QAT)

Train the model with simulated int8 rounding inserted into the forward
pass during training. The optimiser then learns weights that are
*robust to the rounding errors int8 introduces*, instead of being
surprised by them at deploy time.

The simulation is "fake-quant + straight-through estimator": forward
pass rounds activations and weights to the int8 grid, backward pass
pretends the rounding was identity so gradients flow through normally.

### 2. Per-channel input quantisation

The five obs dimensions have wildly different ranges:

| Dim | Range | LSB at shared scale | LSB with per-channel |
|---|---|---|---|
| `motor_pos` | ±2.2 rad | 0.23 (12 distinct values) | 0.014 (164 values) |
| `sin(theta)` | ±1.0 | 0.23 (8 distinct values) | 0.008 (256 values) |
| `cos(theta)` | ±1.0 | 0.23 (8 distinct values) | 0.008 (256 values) |
| `motor_vel` | ±15 rad/s | 0.23 | 0.029 |
| `pen_vel` | ±30 rad/s | 0.23 | 0.229 |

A *shared* obs scale, set by the largest-range dim (`pen_vel` reaching
±30 rad/s during swing-up), crushes `sin(theta)` and `cos(theta)` to
4 distinct int8 values right at the equilibrium where they need maximum
precision. Giving each obs dim its **own** scale recovers ~30× finer
LSB on the small-range dims without losing range on the big-range dims.
This was the single biggest unlock — it's the difference between
"can't hold balance" and "balances".

### 3. Per-row weight quantisation

For each Linear layer, give each output neuron's row of weights its
*own* scale rather than sharing a single scale across the whole weight
matrix. Different output neurons have different weight magnitudes, and
forcing them to share one scale wastes precision on the rows whose
maximum is far below the global max. Standard TFLite-Micro pattern.

The rescale to the next layer's int8 input becomes per-output-channel
too — instead of one fixed-point multiplier `M_q15`, the Arduino has
an array of them, looked up per output neuron during the matmul.

### 4. Bias quantisation to int32, not int8

Biases live in the int32 *accumulator* on the deployed path, where they
get added to `sum_j (W_int8[i,j] × x_int8[j])` before rescale. The
"step size" the bias rounds to is `s_w × s_x` (the accumulator unit),
which is much smaller than 1 — typical bias values are integer
multiples of `s_w × s_x` in the *thousands*.

The first attempt used the same int8 fake-quant for biases as for
weights, which **clamped them to ±127 × s_w × s_x**. For typical layer
3 with `s_w × s_x ≈ 6e-4`, a bias of 0.1 → quantised to 170 → clamped
to 127 → loses 25% of its value. Catastrophic. The fix is a separate
"int32 fake-quant" that rounds to the grid but doesn't clamp. (We use
±2³⁰ as a safety bound; biases are O(10²) at worst.)

### 5. Skip pre-tanh quantisation

The output layer's activation goes through `tanh`. The first attempt
quantised the pre-tanh value to int8 too (matching what a hypothetical
LUT-based deploy would do). But the deploy path doesn't use a LUT — it
dequantises the int32 accumulator straight to float and calls libm
`tanhf`. So QAT shouldn't quantise pre-tanh either; doing so trains
the weights to compensate for a precision loss the deploy never sees,
which makes things worse.

`tanh` is called once per inference on the AVR (~200 cycles) so a
float-based final layer is essentially free.

### 6. Layer-1 absorbing

Per-channel input quantisation (trick 2) gives each obs dim its own
scale `s_obs[j]`. Per-row weight quantisation (trick 3) gives each
output row its own scale `s_w[i]`. Combined, the matmul `y = Wx + b`
expands to:

```
y[i] = sum_j (s_w[i] × W_int[i,j]) × (s_obs[j] × x_int[j])
     = sum_j  s_w[i] × s_obs[j] × W_int[i,j] × x_int[j]
```

Each term has a *different* scale (`s_w[i] × s_obs[j]`), so we can't
factor a common multiplier and apply it once after the sum. That would
break the simple "int matmul + per-row rescale" pattern that makes int8
fast on AVR.

The trick: at *export time* (not at runtime), pre-multiply the weights
by the per-channel input scales:

```
W_eff[i,j] = W[i,j] × s_obs[j]                ← columns stretched by their input scale
W_eff_int[i,j] = round(W_eff[i,j] / s_w_eff[i])   ← then per-row quantise
```

Then the Arduino runs ordinary int8 matmul + per-row rescale:

```
accum[i] = sum_j  W_eff_int[i,j] × x_int[j]
y[i]     = accum[i] × s_w_eff[i]
```

Same answer, but the per-channel input scales have been "absorbed" into
the weight matrix. The Arduino never sees `s_obs` directly at runtime;
that information is folded into `W_eff_int` at compile time. Free at
runtime, just a bit of extra work in `export_weights_quantised.py`.

## Final result

End-to-end on the rig with all six tricks layered together:

| Variant | val_mse | Mean upright (tethered) |
|---|---|---|
| Float H=16 (production reference) | 0.040 | 0.946 |
| Naive int8 H=16 (per-tensor everything) | 0.080 | 0.706 |
| Naive int8 H=32 (more capacity, same noise) | 0.088 | 0.696 |
| **Per-channel int8 H=16** (with all tricks) | **0.045** | **0.934** |
| **Per-channel int8 H=32** (with all tricks) | **0.040** | **0.951** |

**Production:** int8 H=32 with QAT + tricks 1–6, scoring 0.951 mean
upright tethered — within trial-to-trial noise of the float baseline,
at ~0.4 ms inference on the AVR (vs ~15 ms float). 1.5 KB of weights
(4× smaller than float). On-device int8 is the standalone-deployment
path going forward. The float build (`#define POLICY_QUANTISED`
unset) is preserved as the comparison reference.

One observable difference at deploy: the int8 student tends to land at
the "active correction" attractor (small but persistent motor
oscillations during balance) while the float student more often lands
at the "calm" attractor (motor essentially stationary at a fixed
offset). Both balance equivalently well; the choice is set by SAC
training noise — see [`control_rate_selection.md`](control_rate_selection.md)
for the attractor split's underlying dynamics.

## Why bother — what int8 actually unlocks

Fair question once we've seen them side-by-side: float H=16 already
balances at 0.95 with calmer motor behaviour, so what does the 36×
faster int8 path buy on *this* rig?

For the immediate task (balance + swing-up at 35 Hz on the markovian
obs we have), almost nothing — float H=16 has plenty of latency
margin and the calm attractor it tends to land in is qualitatively
nicer than the int8 student's active correction. The two practical
reasons quantisation matters here anyway:

### 1. Bigger inputs and richer architectures aren't gated by latency

The float H=16 student takes ~5 ms per inference, well inside the
28.6 ms control-tick budget. Most expansions we might want push
that number close to or past the budget:

| Architecture change | Float inference | Int8 inference |
|---|---|---|
| Frame stacking (N=4 → 20-dim obs, MLP H=32) | ~7 ms | ~0.3 ms |
| GRU H=16 (recurrent layer) | ~25 ms | ~1 ms |
| MLP H=64 (richer feedforward) | ~50 ms | ~1.5 ms |

**Honest caveat about the upside**: we can't claim any of those
expansions *would* improve this rig. The current float student
already scores 0.95+ tethered, which is plausibly bumping against
the hardware noise floor (12-bit AS5600 ≈ 0.09° resolution,
AccelStepper microstep quantisation ≈ 0.225°, bearing transients).
A GRU *could* learn to self-calibrate encoder drift, but the rig
doesn't visibly suffer from it. Frame stacking *could* smooth
velocity estimates, but the obs already includes filtered velocity.
Whether either gives a measurable performance gain is hopeful, not
proven.

So the honest framing: int8 is **infrastructure that doesn't
preclude future experiments**, not infrastructure that guarantees
gains today. The day we want to try frame stacking (~one day of
work) or a GRU (multi-day framework migration since SB3 doesn't
ship recurrent SAC — would need CleanRL or Tianshou), the inference
budget will already be there. Without int8, both experiments are
gated by inference time even on this microscopic policy.

### 2. Educational / portfolio value

A working int8-on-AVR pipeline is the canonical mobile-ML deployment
recipe in miniature — a project credential and a natural climax for
the "how far down does this rabbit hole go" arc.

## Why anyone quantises at all (broader context)

For *this* rig, the int8 speedup is the rare case where the benefit
shows up directly in compute time, because the ATmega328P has no FPU
— every float multiply is software-emulated, so int8's hardware
multiply path is roughly 36× faster. On modern hardware (a phone, a
server GPU, even a Raspberry Pi), float math is fast and the speedup
looks much more subtle. The technique is *everywhere* in production
ML anyway, because three other forces start to dominate:

- **Memory bandwidth, not compute, is the bottleneck on accelerators.**
  An A100 can do ~10 TFLOPS of fp32 but only fetches ~2 TB/s from
  HBM. A 70 B-parameter LLM at fp32 (280 GB) takes ~140 ms *just to
  load the weights through memory once*. At int4 (35 GB) the same
  fetch is ~17 ms. The arithmetic doesn't get cheaper, but feeding
  the silicon does — and that's almost always the binding constraint.
- **Energy and battery life.** An int8 multiply uses roughly 4× less
  energy than an fp32 one (silicon area + switching activity). For
  server fleets serving billions of inferences a day, that's millions
  of pounds of electricity. For battery-powered devices it's the
  difference between an hour and a day of usable inference.
- **Specialised hardware paths.** NVIDIA Tensor Cores, Apple's Neural
  Engine, Google TPUs all have *much* faster int8 / int4 / fp8
  pipelines than fp32 — typically 4–8× the throughput. The whole
  reason on-device LLMs (phones running Llama-3, MacBooks running
  Mistral) exist is that quantisation maps the model into the
  silicon's fast paths. Without int4, a 70 B model wouldn't fit on
  a 64 GB MacBook in the first place.

So on a tiny MCU the win is **compute time** (no FPU); on a phone
it's **power and memory size**; in the cloud it's **$$/token and
latency**. The technique is the same; what binds varies with the
hardware:

| Where it runs | What's actually being saved | Why people quantise |
|---|---|---|
| **Arduino Nano (us)** | Software-float multiply cycles | Compute is the binding constraint |
| **Phone running Llama-3** | RAM (4× smaller weights) + Neural Engine throughput | A 70 B fp32 model = 280 GB. Doesn't fit. Period. |
| **Cloud serving GPT-class** | Memory bandwidth (HBM fetches), $$/token | int4/int8 → 4–8× more tokens per GPU-hour |
| **Edge device (drone, doorbell, watch)** | Battery life | int8 multiply ≈ 4× less energy than fp32 |

Our rig is the rare case where the benefit shows up most directly —
but the same recipe (QAT, per-channel scales, weight absorption) is
what runs Llama-3 on a phone, just at a much larger scale.

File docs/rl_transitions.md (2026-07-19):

# RL Transitions, in Plain English

What one `(s, a, r, s')` tuple in this project actually contains, end to
end. Reference both for sim (`pendulum_env.py`) and real-device
(`real_env.py`) environments — they're identical by design so a
sim-trained checkpoint can keep learning on the real rig without any
adapter.

## The setup in one paragraph

A rotary inverted pendulum (Furuta type). A horizontal arm rotates in
the floor plane, driven by a stepper motor (the "motor" angle). At the
end of that arm hangs a free-swinging pendulum (the "pendulum" angle).
The goal is to swing the pendulum from hanging-down to upright and hold
it there. Every 10 ms the policy sees the current state, picks a
control nudge, and the world moves on.

## Conventions and frame

- **Pendulum angle θ**: 0 means **upright**, ±π means hanging-down.
  We use θ rather than the raw MuJoCo joint angle φ everywhere in the
  observation and reward, because it makes "the goal" trivially `θ=0`.
  Internally `θ = wrap_pi(φ − π)`.
- **Motor angle**: 0 is the calibrated centre at startup. Positive =
  counter-clockwise looking down. Mechanical hard stops at ±135°; we
  clamp commanded targets to ±125° so the policy never asks for a stop
  hit.
- **Control rate**: configurable (`control_freq_hz`). Sim physics
  integrates at 1 kHz under the hood; real env paces wall-clock to
  match. The choice of rate is rig-specific and bounded by motor
  bandwidth and pendulum dynamics — see
  [`control_rate_selection.md`](control_rate_selection.md). The runtime
  enforcement of whatever rate is chosen is described in
  [`async_control_architecture.md`](async_control_architecture.md).

## Observation `s` — what the policy sees (5 floats)

```
s = [motor_pos, sin(θ), cos(θ), motor_vel, pendulum_vel]
```

| Component | Units | Range | Meaning |
|---|---|---|---|
| `motor_pos` | rad | ±2.36 (= ±135°) | Current arm angle from centre |
| `sin(θ)` | — | [−1, 1] | Sine of pendulum-from-upright |
| `cos(θ)` | — | [−1, 1] | Cosine of pendulum-from-upright. **= 1 at the goal**, = −1 hanging down |
| `motor_vel` | rad/s | ±200 | Arm angular velocity |
| `pendulum_vel` | rad/s | ±200 | Pendulum angular velocity |

Why sine + cosine instead of θ directly? θ wraps at ±π, so the policy
network would see a discontinuity right next to one of its operating
points (hanging down). `(sin θ, cos θ)` is a continuous unit-circle
embedding — no jump, no gradient cliff.

**How `s` is built**:

- **Sim** (`pendulum_env.py::_obs`): read `qpos`/`qvel` directly from
  MuJoCo. With domain randomisation on, we additionally quantise the
  pendulum angle to AS5600 LSB (12-bit, ~0.0015 rad) and inject small
  Gaussian noise on positions and velocities — so the sim observation
  pipeline matches what the real rig actually delivers.
- **Real** (`real_env.py::_build_obs`): poll the LowLevelServer over
  serial → un-flip the firmware's sign convention → finite-difference
  the velocities and run them through a 20 Hz low-pass filter. The
  filter is critical: raw finite-difference at 100 Hz on a noisy
  encoder is unusable.

## Action `a` — what the policy outputs (1 float)

```
a ∈ [−1, 1]
```

The action is **not a torque or a position**. It's a normalised *delta*
applied to the motor's commanded target each step:

```
motor_target ← clip(motor_target + a · max_action_delta_rad, ±125°)
```

So the policy steers the motor by issuing per-step nudges. The `clip`
enforces the soft motor limit so the policy literally cannot command a
hard-stop hit, even if it wants to.

`max_action_delta_rad` is one of two coupled knobs (the other is
`control_freq_hz`). Their product is the *slew rate* in rad/s, which
must respect the motor's bandwidth — see
[`control_rate_selection.md`](control_rate_selection.md) for the
rationale and recipe.

This action representation has two key benefits:

1. The stepper firmware (AccelStepper) accepts position targets, not
   torques. Mapping action directly to a position-delta matches the
   hardware interface.
2. Smooth-by-construction: between consecutive steps the commanded
   position can change by at most 0.1 rad, regardless of policy
   craziness. This bounds the worst-case actuator slew rate and
   protects the motor from policy exploration during training.

## Transition dynamics — going from `s` to `s'`

In **sim** (per step):

1. Apply the action delay queue (DR samples a 0–N-step delay scaled to
   bracket the rig's measured transport delay; the action that takes
   effect now might be the one the policy chose several steps ago —
   modelling serial RTT + AccelStepper ramp).
2. Update the commanded `motor_target` with the (delayed) action.
3. Apply motor first-order lag (DR samples τ ∈ [0, 10] ms): the
   `motor_applied` value fed to MuJoCo trails the commanded target by
   an exponential of time-constant τ. With τ=0 it's instantaneous.
4. Step MuJoCo physics for one control period at 1 ms substeps.
5. Read out the new state, build `s'`, compute reward.
6. Episode terminates if the motor hits the hard stop at ±135° (incurs
   a `−5` penalty); truncates after `episode_length_s` (default 8 s).

In **real** (per step):

1. Update the commanded `motor_target` with the action (no action delay
   queue — the real hardware *is* the delay).
2. Send `set_target(motor_target)` over serial.
3. Sleep until the next tick (paces wall-clock to control rate).
4. Read state from the rig: `(time_us, motor_pos, pendulum_pos)`.
5. Finite-diff + low-pass filter the velocities.
6. Build `s'`, compute reward.
7. Terminate on |motor_pos| ≥ 135° (firmware also enforces this in
   hardware as a backstop); truncate after `episode_length_s` (default
   6 s during fine-tuning).

The key sim-to-real bridge is that **the firmware's transport delay,
acceleration ramp, and stepper friction are what the sim's
`action_delay_steps`, `motor_tau_s`, and joint friction parameters are
modelling**. Domain randomisation samples those over plausible ranges
each episode so the policy has seen enough variation to handle the
real point.

## Reward `r` — what we're rewarding

The current reward is the **standard Quanser quadratic-cost form**
(common in Furuta-pendulum literature):

```
r = −[ θ² + k_θ̇·θ̇² + k_α·α² + k_α̇·α̇² + k_a·a² ]
```

where:

- **θ** = pendulum-from-upright (rad). The dominant term: `θ²` is 0
  at the goal and ≈ π² ≈ 9.87 at hanging-down.
- **θ̇** = pendulum_vel. Small `k_θ̇=0.001` weight discourages
  spinning through upright forever.
- **α** = motor_pos (rad, sim's misnamed-from-Quanser variable).
  `k_α=0.5` keeps the policy near centre.
- **α̇** = motor_vel. `k_α̇=0.005` discourages frantic arm motion.
- **a** = action ∈ [−1, 1]. `k_a=0.05` light penalty for jerky control.

Reward is **purely non-positive** — max 0 when fully balanced still at
centre with no motor activity, around −10 per step at hanging-down.
SAC handles negative rewards fine, and the all-negative signal makes
"less negative" gradient toward upright unambiguous.

**What the policy actually learns to do:**

- *Far from upright*: Pump the arm back and forth. The `θ²` term
  rewards getting upright; the `α²` and `α̇²` penalties keep the
  pumping bounded so it doesn't slam into the limits.
- *Near upright*: Hold still. The dominant `θ²` term goes near zero
  there, leaving only the small velocity/action penalties as residuals
  — so the policy is rewarded for any state close to (θ=0, θ̇=0,
  α=0, α̇=0).

If the policy gets the pendulum near upright but not still, the cost
is dominated by `k_θ̇·θ̇²`. If it balances but with the arm wandering,
the cost is dominated by `k_α·α²`. These weights are what shape the
policy from "wobbly catch" toward "smooth hold".
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

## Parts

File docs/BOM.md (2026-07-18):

# Bill of Materials

Components needed to build one rotary inverted pendulum. Last updated 2026-05-25.

## Sommaire

This document has **two alternative sourcing sections** for the same build —
pick one, don't mix them casually (specs/tolerances differ between listings):

- [AliExpress / UK (original)](#aliexpress--uk-original) — the original
  upstream sourcing, cheapest.
- [Amazon France (as-built sourcing)](#amazon-france-as-built-sourcing) —
  what was actually used to build this specific rig, fast delivery from
  France.

## AliExpress / UK (original)

**Cost estimate**  
One complete rig comes in at **under £20** in parts (~£14 electronics + ~£5 mechanical) — over 230× cheaper than the £4,500 Quanser QUBE.

**Design rationale**  
For *why* each electronics component was chosen (power supply
sizing, motor selection, driver tradeoffs, decoupling, etc.), see
[`electronics_design.md`](electronics_design.md). This BOM is a pure
procurement reference.

**Suppliers**  
Unless otherwise noted, items were sourced from AliExpress.
The only exception is the Bones Reds skate bearing (Amazon UK).

**Variant selection**  
Several AliExpress listings sell multiple variants from a single
product page (e.g., bearing ZZ vs RS, stepper body length, switch
colour/rating, with/without included accessories). The page's default
selection is **not always** the right one — always check the **Spec**
column below and pick the matching variant before adding to cart.

### Electronics

| Item | Spec | Price (£) | Source | Notes |
| --- | --- | --- | --- | --- |
| Microcontroller | Arduino Nano (ATmega328P, 16 MHz, CH340, USB-C) | £1.60 | [AliExpress](https://www.aliexpress.com/item/1005006053215107.html) | Any clone works; original 32 KB flash / 2 KB SRAM constraints assumed in firmware. |
| Stepper motor | NEMA17 17HS4023, 1 A rated, 22 mm body | £4.48 | [AliExpress](https://www.aliexpress.com/item/1005006111249881.html) | Short-body variant. |
| Stepper driver | DRV8825 (or A4988 / TMC2209) | £1.43 | [AliExpress](https://www.aliexpress.com/item/10000278156894.html) | Set Vref to 0.485 V (≈ 0.9 A current limit, 90 % of motor rating). |
| Magnetic encoder | AS5600 12-bit on I²C (with diametric magnet) | £1.04 | [AliExpress](https://www.aliexpress.com/item/1005006349632569.html) | Reads pendulum angle. RobTillaart Arduino library. Module ships with a small diametrically-magnetised disc that sits on the pendulum shaft end facing the AS5600 face. |
| Power adapter | 12 V, 2 A barrel (5.5 × 2.1 mm, UK plug) | £2.59 | [AliExpress](https://www.aliexpress.com/item/1005006467110035.html) | Powers the 12 V rail; Arduino 5 V comes from the Nano's regulator. |
| DC barrel jack | 5.5 × 2.1 mm panel-mount socket | £0.12 | [AliExpress](https://www.aliexpress.com/item/1005003324016159.html) | Board-side power input. |
| Power switch | SPST rocker, 20 mm round, 12 V DC | £1.24 | [AliExpress](https://www.aliexpress.com/item/1005005944839290.html) | Inline on the 12 V rail; turns the rig on/off without unplugging. |
| 100 nF ceramic cap | 104 monolithic ceramic | £0.01 | [AliExpress](https://www.aliexpress.com/item/1005005691676032.html) | Across the 12 V rail near the driver. |
| 22 µF electrolytic cap | 25 V, aluminium electrolytic | £0.02 | [AliExpress](https://www.aliexpress.com/item/1005005945738204.html) | Bulk decoupling on the 12 V rail. |
| Protoboard | 40 × 60 mm, double-sided | £0.26 | [AliExpress](https://www.aliexpress.com/item/1005005945712659.html) | All electronics live here. |
| Header pins | Female, 2.54 mm pitch, 1×40 strip | £1.12 | [AliExpress](https://www.aliexpress.com/item/1005006034877497.html) | For mounting the Nano + driver as removable modules. |

### Mechanical

| Item | Spec | Price (£) | Source | Notes |
| --- | --- | --- | --- | --- |
| Ball bearing | **Bones Reds 608** (8 × 22 × 7 mm precision skate bearing) | £2.50 | Amazon UK | Single bearing at the arm/pendulum joint, after simplifying away the dual-bearing design. Skate bearings are designed for low friction and trivially deshield-and-relube. |
| Ball bearing (budget) | 608ZZ 8 × 22 × 7 mm (shielded — **avoid the 608RS variant**) | £0.18 | [AliExpress](https://www.aliexpress.com/item/1005005778152535.html) | Workable budget alternative. The same listing also sells a 608RS (rubber-sealed) variant — the RS bearings had noticeably more drag/stiction and should be avoided. ABEC-7 marking on bulk lots is meaningless; precision skate bearings (Bones Reds or equivalent) are still preferred for lowest friction. |
| 3D-printed parts | Arm, base, lid, pendulum link (with embedded coin), encoder boss | ~£2.00 (filament) | — | Self-printed. <100 g PLA at ~£20/kg. STL files in `meshes/`; [OnShape source](https://cad.onshape.com/documents/fa8afe5031ca70c78442e408/w/5519455d45464bacd4cf9b1d/e/79273ac76c3305af463951de). The whole assembly is **press-fit** — no fasteners required. Pendulum link mass, COM, and inertia tensor live in `urdf/model.urdf` (exported from Onshape with PLA-density-corrected materials) — the RL sim and the sysid pipeline both read from there. |
| 2p coin (UK) | UK 2-pence piece, 7.12 g, 25.91 × 2.03 mm | £0.02 | — | Press-fit into the pendulum link as the tip mass. Its mass, COM, and inertia are baked into the pendulum link inertia exported from Onshape — see `urdf/model.urdf`. |
| Motor heatsink | Aluminium extruded, NEMA17 / 42 mm pattern | £0.55 | [AliExpress](https://www.aliexpress.com/item/4000723868050.html) | Sticks onto the back face of the motor. Keeps the motor cool during extended training sessions. |

### Tools (reference, not part of unit cost)

- Soldering iron + 60/40 leaded solder (or lead-free if preferred)
- 3D printer (PLA / PETG, 0.4 mm nozzle, 0.2 mm layer)
- Multimeter (continuity + Vref pot trim)
- [30 AWG solid-core wire kit](https://www.amazon.co.uk/gp/product/B0C2Z4FNN5) (5-roll set, Amazon UK)

---

## Amazon France (as-built sourcing)

The sections above are the original upstream BOM and are left as-is. This
section documents how **this specific rig** was actually sourced — mostly
Amazon.fr instead of AliExpress/Amazon UK, plus a few parts added along the
way (post-incident protection, in-arm sensor wiring, a stripboard swap).

**Cost estimate** — Electronics ~€220 + mechanical ~€32 for this basket.
This is bulk-kit list pricing (caps, resistors, headers, crimp terminals,
wire all bought as multi-use kits), not a true marginal per-rig cost — most
kits cover several builds.

### Electronics

| Item | Spec | Price (€) | Source | Notes |
| --- | --- | --- | --- | --- |
| Microcontroller | Arduino Nano (ATmega328P, 16 MHz, CH340, USB-C) | €11.99 | [Amazon.fr](https://www.amazon.fr/dp/B0D8WGSPW3) | AZDelivery, pre-soldered + USB-C cable. |
| Stepper motor | NEMA17 17HE08-1004S, 1 A rated, 23 mm body | €15.26 | [Amazon.fr](https://www.amazon.fr/dp/B0B93PNYCP) | STEPPERONLINE pancake, 17 Ncm, 1.8°/step. 23 mm vs. 22 mm spec — no impact (checked against STL). |
| Stepper driver | DRV8825 + heatsink (pack of 2) | €6.99 | [Amazon.fr](https://www.amazon.fr/dp/B08BF9KTN9) | AZDelivery. Vref ≈ 0.485 V. 1 used, 1 spare. |
| Magnetic encoder | AS5600 12-bit on I²C, pack of 2, with diametric magnet | €9.49 | [Amazon.fr](https://www.amazon.fr/dp/B0B778L7T3) | Hailege clone — behaves differently from the original Seeed module (direct TWI polling + 100 kHz bus needed instead of the Wire lib; see firmware). 1 unit damaged 09/07 (frozen I²C bus), 1 spare to install. |
| Power adapter | 12 V, 2.5 A barrel (5.5 × 2.1 mm, EU plug) | €16.00 | [Amazon.fr](https://www.amazon.fr/dp/B09LGZ3SVP) | — |
| DC barrel jack | 5.5 × 2.1 mm panel-mount socket | €8.99 | [Amazon.fr](https://www.amazon.fr/dp/B07ZTJXHC6) | Board-side power input. Wired via crimp terminals, see below. |
| Power switch | SPST rocker, 20 mm round, 12 V DC (pack of 10) | €8.99 | [Amazon.fr](https://www.amazon.fr/dp/B09VZ74QCL) | Wired via crimp terminals, see below. |
| Crimp terminal kit | 280-pc assorted spade/ring/fork terminals, M+F | €9.98 | [Amazon.fr](https://www.amazon.fr/dp/B09WDT6469) | Added vs. original BOM. Quick-disconnect crimp wiring to the power switch and barrel jack instead of direct soldering — keeps that wiring serviceable. |
| 100 nF ceramic cap | 104 monolithic ceramic (kit of 360, 12 values) | €6.99 | [Amazon.fr](https://www.amazon.fr/dp/B0CLRLBW19) | 1 used from kit. |
| 22 µF electrolytic cap | 25 V, aluminium electrolytic (kit of 630, 24 values) | €17.99 | [Amazon.fr](https://www.amazon.fr/dp/B07PN5P64W) | 1 used from kit. Superseded near the driver by the 220 µF/35 V cap below. |
| 220 µF electrolytic cap  | 35 V, aluminium electrolytic (kit) | €7.99 | [Amazon.fr](https://www.amazon.fr/dp/B0CMQCG3M8) | Added vs. original BOM. Added after the 05/07 USB incident — bulk decoupling at the DRV8825; the 22 µF/25 V cap above only reaches 25 V, not enough headroom. |
| Series resistors | 1/4 W kit, 25 values (1 Ω – 1 MΩ) | €8.99 | [Amazon.fr](https://www.amazon.fr/dp/B0BTP88DZN) | Added vs. original BOM. 3× 100–220 Ω in series on STEP/DIR/EN — post-incident protection. |
| TVS diode | 1.5KE18A, unidirectional | €4.60 | [Amazon.fr](https://www.amazon.fr/dp/B0DD4F8L2W) | Added vs. original BOM. On the 12 V rail near the DRV8825 — post-incident protection. |
| USB isolator | 5 kV galvanic isolation (ISOUSB211-based) | — | [Amazon.fr](https://www.amazon.fr/dp/B0FR4SW7ML) | Added vs. original BOM. Jhoinrch RH-07B, between PC and Arduino — the one part the PC's safety actually depends on after the incident. |
| Protoboard | 50 × 100 mm, single-sided copper stripboard (pack of 25) | €17.42 | [Amazon.fr](https://www.amazon.fr/dp/B085WJ7535) | **Replaces the original double-sided 40×60 mm protoboard.** Rademacher stripboard, 2.54 mm grid — matches the actual soldered layout (see `diagrams/`). |
| Header pins | Male + female, 2.54 mm pitch, 40-pin single row (pack of 30) | €11.71 | [Amazon.fr](https://www.amazon.fr/dp/B07DBY753C) | For mounting the Nano and DRV8825 as removable/socketed modules. |
| Wire (main harness) | 22 AWG solid-core, 6 colours × 9 m | €19.99 | [Amazon.fr](https://www.amazon.fr/dp/B07V5FVSYL) | — |
| Wire (in-arm sensor) | 30 AWG solid-core, 6 colours × 30 m | €19.99 | [Amazon.fr](https://www.amazon.fr/dp/B0C2Z4FNN5) | Promoted from the "Tools" list above to a proper component row. Used for the AS5600 wiring **inside the arm** — thinner/more flexible than the 22 AWG harness, needed to route through the arm without adding stiffness at the joint. |

### Mechanical

| Item | Spec | Price (€) | Source | Notes |
| --- | ---| --- | --- | --- |
| Ball bearing | 608ZZ 8 × 22 × 7 mm, shielded (pack of 20) | €9.45 | [Amazon.fr](https://www.amazon.fr/dp/B09TQG47KQ) | QWORK. Budget option (not Bones Reds). |
| Bearing grease | White lithium grease spray, 400 ml | €12.95 | [Amazon.fr](https://www.amazon.fr/dp/B01G12I1VU) | Added vs. original BOM. WD-40 Specialist — relube for the 608ZZ bearings after deshielding. One can covers many rebuilds. |
| Motor heatsink | Aluminium, 40 × 40 × 11 mm (pack of 4) | €8.79 | [Amazon.fr](https://www.amazon.fr/dp/B0BFW4T8SW) | — |
| 3D-printed parts | unchanged from original | ~€2 (filament) | — | Self-printed. Unchanged. |
| 2p coin (UK) | unchanged from original | €0.50 × 2 | eBay.fr | Unchanged. |

### Tools (reference, not part of unit cost)

- Soldering iron + solder — Miniware TS101 or Yihua station
- 3D printer: Bambu Lab A1 mini + PLA Basic filament
- Multimeter (continuity + Vref pot trim)
- Post-incident protection parts (USB isolator, TVS diode, series resistors, 220 µF cap) are listed under Electronics above, not here — they're part of every build now, not optional tooling.

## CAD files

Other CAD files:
meshes/motor plate.stl
meshes/base.stl
meshes/arm.stl
meshes/lid.stl
meshes/pendulum.stl

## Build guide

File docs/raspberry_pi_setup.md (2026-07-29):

# Setting up a Raspberry Pi 3B+ for the unattended demo

Step-by-step guide to turn a brand-new Raspberry Pi 3B+ into the piece
that flashes the Nano, waits for 12V and USB to be plugged in (in any
order), and starts the balance policy — no screen or keyboard needed once
it's set up. That runtime behavior is `tools/pi_demo/`'s job (see
[`tools/pi_demo/README.md`](../tools/pi_demo/README.md)); this document
covers everything *before* that: preparing the SD card, installing
dependencies on the Pi, and wiring the rig physically.

## 1. Hardware needed

- Raspberry Pi 3B+
- micro SD card ≥ 8 GB (16-32 GB recommended), class 10
- Official Pi power supply: 5V / 2.5A micro-USB (an undersized supply
  causes random reboots under load — the #1 cause of ghost bugs on a Pi
  3B+)
- USB cable to connect the Pi to the Nano (same connector as pictured in
  `docs/BOM.md` — Micro-USB or USB-C on the Nano side depending on the
  clone)
- The assembled rig with its 12V power supply (see `docs/BOM.md` and
  `docs/electronics_design.md`)
- A computer to flash the SD card (Windows/macOS/Linux, doesn't matter)
- Optional: HDMI screen + keyboard for the first boot (otherwise
  everything is done headless over SSH, see step 2)

## 2. Flash the SD card

1. Install [Raspberry Pi Imager](https://www.raspberrypi.com/software/)
   on the computer.
2. Insert the micro SD card.
3. In Raspberry Pi Imager:
   - **Device**: Raspberry Pi 3
   - **OS**: *Raspberry Pi OS Lite (64-bit)* — no need for a desktop
     environment since the Pi will run headless; it also leaves more RAM
     free for PyTorch/stable-baselines3.
   - **Storage**: the inserted SD card
4. Click the gear icon (⚙️, "Edit Settings" / advanced options) **before**
   writing the image, and configure:
   - Hostname (e.g. `pendulum-pi`)
   - Enable SSH → "Use password authentication" (or a public key if you
     have one)
   - Username + password
   - Wi-Fi (SSID + password + country) if the Pi isn't on Ethernet
   - Timezone / keyboard layout
5. Write the image, wait for verification, eject the card.

These settings avoid any physical screen/keyboard: the Pi boots straight
into SSH on the right network.

## 3. First boot and connection

1. Insert the SD card into the Pi, plug in the official power supply
   (not the rig yet).
2. Wait ~1-2 min for the first boot (filesystem expansion, automatic
   reboot).
3. Connect:
   ```bash
   ssh <username>@pendulum-pi.local
   ```
   (or the IP directly if `.local`/mDNS doesn't resolve on your network).
4. Update the system:
   ```bash
   sudo apt update && sudo apt full-upgrade -y
   sudo reboot
   ```

## 4. System dependencies

```bash
sudo apt install -y git python3-venv python3-pip curl
```

**arduino-cli** (needed to flash the Nano from the Pi):

```bash
curl -fsSL https://raw.githubusercontent.com/arduino/arduino-cli/master/install.sh | sh
sudo mv bin/arduino-cli /usr/local/bin/
arduino-cli core update-index
arduino-cli core install arduino:avr
arduino-cli lib install FastAccelStepper AS5600
```

Confirm the Nano is actually seen once plugged in over USB (step 7) with
`arduino-cli board list`.

## 5. Clone the repository

For a Pi dedicated purely to running the demo (no training), the `demo`
branch is enough — it only carries the firmware, the reference policies,
and `tools/pi_demo/`:

```bash
git clone --branch demo --single-branch \
    https://github.com/csileo/rotary-inverted-pendulum.git
cd rotary-inverted-pendulum
```

## 6. Python environment

```bash
python3 -m venv .venv
source .venv/bin/activate
pip install --upgrade pip
pip install -r requirements.txt
```

On a Pi 3B+ (ARM, no GPU), `stable-baselines3` pulls in PyTorch CPU-only
automatically — this can take several minutes, that's expected.

If `pip install` fails partway through the PyTorch download with `OSError:
[Errno 28] No space left on device`, it's very likely not the SD card itself:
`/tmp` on Raspberry Pi OS is often a `tmpfs` (RAM-backed) mount sized at
~50% of RAM, e.g. ~450 MB on a Pi 3B+'s 1 GB — too small for the ~430 MB
PyTorch wheel pip downloads/unpacks there. Confirm with `mount | grep /tmp`,
then point pip at a temp dir on the SD card instead:

```bash
mkdir -p ~/pip_tmp
TMPDIR=~/pip_tmp pip install -r requirements.txt
```

## 7. Plug in the Nano and set up the AS5600 module

1. Plug the Nano into the Pi over USB.
2. `RotaryInvertedPendulum-arduino/LowLevelServer/hw_config.h` is
   deliberately absent from the repo (no safe default — see CLAUDE.md):
   copy the profile matching the AS5600 module mounted on this rig from
   `RotaryInvertedPendulum-arduino/LowLevelServer/hw_profiles/`:
   ```bash
   cp RotaryInvertedPendulum-arduino/LowLevelServer/hw_profiles/as5600_hailege_clone.h \
      RotaryInvertedPendulum-arduino/LowLevelServer/hw_config.h
   # or as5600_seeed.h for an original Seeed module — see docs/BOM.md
   ```
3. Detect the Nano for this specific Pi (do this once, or again if the
   Nano is swapped for one with a different USB-serial chip) — **unplug
   every other USB-serial device before running this**, the script
   assumes exactly one serial device is connected:
   ```bash
   cd tools/pi_demo
   python detect_usb_config.py
   cd ../..
   ```

## 8. Manual test before automating

Before automating anything, confirm the full chain works by hand, with
the rig powered at 12V and the Nano on USB:

```bash
cd RotaryInvertedPendulum-python/src/rl
python run_policy.py --policy models/policy_working_balance.zip \
    --frame-stack 3 --duration-s 30 --port <PORT>
```

`<PORT>`: found with `arduino-cli board list` (typically `/dev/ttyUSB0`
on a Pi). If it compiles/flashes and balances, everything is in place;
move on to automation.

A distilled student MLP is also available as a lighter-weight alternative
to the SAC teacher `.zip` — same balance quality (upright ≈ 0.987 on a Pi
3B+, validated 2026-07-28), much smaller and faster to load. It ships in
two equivalent forms: `student.pt` (PyTorch, needs `distill.py`'s
`StudentMLP`) and `student_numpy.npz` (plain NumPy, bit-exact to the `.pt`
version — see `numpy_student.py`). The `.npz` form never imports
torch/stable-baselines3 at all, which matters a lot here: on a Pi 3B+
that import alone can take several seconds.

```bash
python run_policy.py \
    --policy models/distill_working_balance_h32_dagger/student_numpy.npz \
    --frame-stack 3 --duration-s 30 --port <PORT>
```

All three checkpoint forms are inference-only here — `run_policy.py` still
runs on the Pi itself, not on the Nano; see `models/README.md` for the
distinction and why an actual on-device (standalone) deployment of the
student was not pursued.

## 9. Automate: `tools/pi_demo/run_demo.py`

This is the script that makes the demo tolerant to plug-in order — Pi
power, the pendulum's 12V, and the Nano's USB cable can be plugged in any
order and with any delay between them; it waits out each precondition
instead of failing on the first one missing (see
`tools/pi_demo/README.md`).

Run it once by hand to check:

```bash
cd tools/pi_demo
python run_demo.py
```

Then wrap it in a `systemd` service so it runs automatically on every Pi
boot (e.g. after a power outage):

```bash
sudo tee /etc/systemd/system/pendulum-demo.service > /dev/null <<'EOF'
[Unit]
Description=Rotary inverted pendulum - unattended demo
# No After=network.target: the demo only talks to the Nano over USB
# serial, no network needed, so there's no reason to make boot wait on
# a network link coming up (which can add real seconds, and may never
# resolve at all on a Pi with no Wi-Fi configured).

[Service]
Type=simple
User=<username>
WorkingDirectory=/home/<username>/rotary-inverted-pendulum/tools/pi_demo
ExecStart=/home/<username>/rotary-inverted-pendulum/.venv/bin/python run_demo.py
Restart=on-failure
RestartSec=5

[Install]
WantedBy=multi-user.target
EOF

sudo systemctl daemon-reload
sudo systemctl enable --now pendulum-demo.service
```

Replace `<username>` with the username configured in step 2.
`run_demo.py` itself loops forever — wait for the Nano, flash if needed,
wait for 12V, run the policy for `--duration-s`, pause, repeat — so once
the service is up, the demo keeps re-running on its own with no need to
reconnect (SSH or otherwise) to restart it, e.g. at a booth with no network.
`Restart=on-failure` is just the outer safety net in case `run_demo.py`
itself ever crashes outright. The only way to actually stop it is Ctrl-C
(when run by hand) or `sudo systemctl stop pendulum-demo.service`
(SIGTERM, when run as the service) — a Nano unplug/replug or a finished
run just feeds back into the same loop.

Unlike a naive "wrap the CLI in a loop" implementation, `run_demo.py`
loads the policy and opens its connection to the Nano only once, then
reuses both across every cycle — each fresh serial connection resets the
Arduino (~2s), and repeatedly re-importing torch is slow on a Pi 3B+, so
paying either cost once per boot instead of once per cycle is most of
what makes cycles fast. It only reconnects/reflashes if something
actually breaks (e.g. the Nano gets unplugged).

Optional environment variables (add under `[Service]` with
`Environment=`, see `tools/pi_demo/README.md`):

| Variable | Meaning |
|---|---|
| `PENDULUM_POLICY` | Path to the `.zip`/`.pt`/`.npz` checkpoint to load. Defaults to `models/distill_working_balance_h32_dagger/student_numpy.npz` (no torch import at all); set to `models/policy_working_balance.zip` for the full SAC teacher instead |
| `PENDULUM_FRAME_STACK` | Must match the checkpoint's training frame-stack |
| `PENDULUM_DURATION_S` | How long to balance before stopping (default 30s) |
| `PENDULUM_MOTOR_POWER_TIMEOUT_S` | How long to wait for 12V before giving up |
| `PENDULUM_LOOP_DELAY_S` | Pause between demo cycles (default 10s) |
| `PENDULUM_CONTROL_FREQ_HZ` | Control loop frequency, must match training (default 35.0) |
| `PENDULUM_MAX_ACCEL_RAD_S2` | Action-to-acceleration scale, must match training (default 150.0) |

### Updating to the latest demo

`demo` is a synthetic branch, regenerated wholesale from `main` by
`tools/sync_fork_branches.py` on the dev side (see that script's
docstring) — always fast-forward, so a plain `git pull` normally works.
To force the Pi's checkout to exactly match the latest `demo` and discard
any local drift:

```bash
cd ~/rotary-inverted-pendulum
git fetch origin demo
git reset --hard origin/demo
git clean -fd -e .venv -e RotaryInvertedPendulum-arduino/LowLevelServer/hw_config.h -e tools/pi_demo/usb_config.json
sudo systemctl restart pendulum-demo.service
```

`demo` ships with no `.gitignore` (it's a filtered file list, not a real
dev branch), so a plain `git clean -fd` would also delete files that are
untracked on purpose and specific to this Pi/rig: `.venv`, `hw_config.h`
(copied by hand in step 7 — not regenerable by a pull) and
`usb_config.json` (written by `detect_usb_config.py` in step 7) — the
`-e` excludes above keep those. Watch the demo restart with:

```bash
journalctl -u pendulum-demo.service -f
```

## 10. Physical mounting on the rig

1. Mount the Pi near the rig (e.g. under the base), away from motor
   vibration and cables that could snag the arm.
2. USB cable: Pi → Nano. Long enough not to constrain the arm's
   rotation.
3. Pi power: **separate** from the 12V motor rail — a dedicated
   micro-USB 5V/2.5A wall adapter, on a different outlet or a fixed power
   strip (no loose connection that could pull on the rig's wiring).
4. Pendulum 12V supply: unchanged, see `docs/electronics_design.md` and
   `docs/BOM.md`.
5. Final test: cut all power, then plug everything back in in a
   completely arbitrary order (12V first, or USB first, or Pi first,
   with varying delays between each). The service should wait patiently
   and start balancing as soon as everything is present — watch the logs
   with:
   ```bash
   journalctl -u pendulum-demo.service -f
   ```

## 11. Speeding up Pi boot time

Measure before guessing what's slow:

```bash
systemd-analyze
systemd-analyze blame
systemd-analyze critical-path
```

### Confirmed wins (measured on this Pi: 32.442s → 20.315s userspace, -37%)

1. **Disable cloud-init.** It only provisions the Pi on its very first boot
   (hostname, SSH, Wi-Fi, etc.) — once that's done, re-running it every
   boot was costing ~4.5s directly on the critical path
   (`cloud-init-main` 3.5s + `cloud-init-local` 0.8s + `cloud-init-network`
   0.3s, plus `cloud-config`/`cloud-final` off-path). Doesn't affect
   anything already configured — it just stops re-running:
   ```bash
   sudo touch /etc/cloud/cloud-init.disabled
   ```
2. **Disable `NetworkManager-wait-online.service`.** Nothing on this Pi
   needs a guaranteed "network is up" signal before starting, so this was
   6.8s of pure wasted wait every boot:
   ```bash
   sudo systemctl disable NetworkManager-wait-online.service
   ```
3. **`pendulum-demo.service` doesn't depend on `network.target`** (see
   step 9) — the demo itself needs no network, so it starts and runs
   independent of any NetworkManager slowness regardless of the two points
   above.

Reboot after applying 1 and 2 (`sudo reboot`).

### Tried, no measurable effect — don't bother repeating these

- **Static IP on `eth0` instead of DHCP**: no change (8.797s → 8.778s).
  The DHCP lease itself is already fast (~0.16s); `journalctl -u
  NetworkManager -b` showed the remaining delay isn't DHCP negotiation.
- **Disabling the Wi-Fi radio** (`dtoverlay=disable-wifi` in
  `/boot/firmware/config.txt`): no change either — the same ~6s
  `NetworkManager[...]: manager: startup complete` gap persisted even
  with the Wi-Fi device entirely absent from the logs. Reverted.

What's left (`NetworkManager.service` at ~8.8s, dominated by that ~6s
internal "startup complete" delay) looks like a fixed NetworkManager
startup cost we couldn't trace to DHCP, static IP, or Wi-Fi — chasing it
further would mean retuning NetworkManager itself or switching network
stacks, more effort than it's worth here since `pendulum-demo.service`
doesn't depend on it anyway.

### Untested ideas (not yet tried on this Pi)

- Disable services this Pi doesn't use: `sudo systemctl disable bluetooth
  hciuart triggerhappy` (and `avahi-daemon` too, unless you rely on
  `pendulum-pi.local` to SSH in — see step 3).
- The SD card itself is usually the single biggest lever: an A1/A2-rated
  card boots noticeably faster than a generic one. If this Pi 3B+ supports
  USB boot, an SSD is a bigger jump still, but that's a full re-provision,
  not a quick tweak.

## 12. Troubleshooting

- **`arduino-cli board list` doesn't see the Nano**: faulty USB cable
  (common with "charge only" cables), or a USB-serial chip (CH340 etc.)
  without a driver — rare on Raspberry Pi OS, which already ships the
  usual drivers.
- **`flash_if_needed.py` refuses to compile**: `hw_config.h` is missing —
  go back to step 7.
- **"Timed out waiting for motor power"**: check that the 12V adapter is
  plugged in and the rig's power switch (if present, see BOM) is on;
  otherwise a driver/Vref/enable wiring fault — see
  `docs/electronics_design.md`.
- **The service keeps restarting**: `journalctl -u
  pendulum-demo.service -f` for the exact error; most often a wrong
  venv/policy path in the service file.
- **Flaky USB detection after swapping the Nano**: rerun
  `detect_usb_config.py` (step 7) with only one serial device plugged in.

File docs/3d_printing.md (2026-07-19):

# 3D Printing Notes

Practical notes for printing the mechanical parts. STL files live in
[`../meshes/`](../meshes); the OnShape source is linked from
[`BOM.md`](BOM.md).

## Settings

PLA or PETG, 0.4 mm nozzle, 0.2 mm layer (Bambu Studio defaults). Use
'Tree' supports for the enclosure (base, lid) and the arm.

## Pendulum link — pause printing to insert the coin

The pendulum link has a slot sized for a UK 2-pence coin (7.12 g) as the
tip mass. Configure your slicer to **pause on layer 21** — drop the coin
into the slot, then resume. The next layers seal it in.

If you skip the pause, the link prints with an empty void where the coin
should be: its mass and inertia then disagree with what
[`urdf/model.urdf`](../urdf/model.urdf) says, and the policy will not
transfer from sim.

## Soldering note

Cut your hookup wires slightly longer than you think you'll need. Excess
length is trivial to manage; a wire that's a few millimetres too short
turns the next solder joint into a fight.

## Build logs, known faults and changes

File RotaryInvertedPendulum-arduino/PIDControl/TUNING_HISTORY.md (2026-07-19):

# PID Tuning History

This document tracks the iterative tuning process for the PID balancing controller.

## Hardware Setup
- **Motor:** NEMA17 stepper with DRV8825 driver, 8x microstepping (1600 steps/rev)
- **Encoder:** AS5600 magnetic encoder (12-bit, 4096 counts/rev)
- **Controller:** Arduino Nano (ATmega328P, 16MHz)
- **Motor limits:** ±90° from starting position (wire constraint, no slip ring)

## Control Architecture
- State machine: WAITING → BALANCING (engages within ±25° of vertical)
- PID output controls motor position (not velocity)
- Low-pass filter on pendulum angle before PID calculation
- Anti-windup on integral term with limit and decay at motor limits

---

## Iteration 1: Original Ziegler-Nichols Values

**Date:** 2025-01-10

**Parameters:**
| Parameter | Value |
|---|---|
| Kp | 1.2 (0.6 × Ku, where Ku=2.0) |
| Ki | 24.0 (2 × Kp / Tu, where Tu=0.1) |
| Kd | 0.015 (Kp × Tu / 8) |
| Filter | 500 Hz |
| Motor MaxSpeed | 200000 |
| Motor Accel | 100000 |

**Bugs found in code review:**
- Integer division bug: `controlPeriod = 1/1000 = 0` (always true condition)
- No integral anti-windup
- Motor limit just froze instead of clamping
- Tare function did nothing

**Observations:**
- Motor drifted heavily toward ±90° limits
- Hit saturation and lost balance
- Balanced for ~6 seconds before falling
- Integral wind-up caused persistent drift

---

## Iteration 2: Reduced Ki, Increased Kd

**Date:** 2025-01-10

**Parameters:**
| Parameter | Value | Change |
|---|---|---|
| Kp | 1.2 | - |
| Ki | 6.0 | ↓ from 24.0 |
| Kd | 0.03 | ↑ from 0.015 |
| Filter | 500 Hz | - |

**Observations:**
- Motor no longer saturating at ±90° (stayed within ±60°)
- Motor returns toward center after falls
- Still very oscillatory during balance attempts
- Rapid oscillations ~±20-30° not decaying
- System on edge of stability

**Diagnosis:** Insufficient damping, derivative amplifying high-frequency noise

---

## Iteration 3: More Damping, Lower Filter

**Date:** 2025-01-10

**Parameters:**
| Parameter | Value | Change |
|---|---|---|
| Kp | 1.0 | ↓ from 1.2 |
| Ki | 6.0 | - |
| Kd | 0.08 | ↑ from 0.03 |
| Filter | 100 Hz | ↓ from 500 Hz |

**Observations:**
- High-frequency oscillations eliminated (filter working)
- Motor stays within ±60° (no saturation)
- Best stable period at end of run with ~±10-15° error
- Still falling and needing recovery multiple times
- Slower oscillations remain during balance
- Clear improvement over previous iterations

**Diagnosis:** Better, but still needs more damping or less aggression

---

## Iteration 4: Bug Fix + Enhanced Diagnostics

**Date:** 2025-01-10

**Bug fixes applied:**
- Fixed first-loop timing bug: `prev_time_us` now initialized in `setup()` to avoid huge dt on first iteration
- This was causing derivative spikes and filter miscalculation on startup

**Enhanced data collection:**
- Now collecting individual PID terms (P, I, D) for diagnosis
- Added state (WAITING/BALANCING) to output
- New plot: `plot_pid_terms.png` shows each term over time

**Parameters:** Same as Iteration 3 (Kp=1.0, Ki=6.0, Kd=0.08, Filter=100Hz)

**Next:** Run with bug fixes to establish new baseline, then continue tuning.

---

## Iteration 5: Timing Optimization & Fixed 1 kHz Loop

**Date:** 2025-01-10

**Problem:** Loop timing was inconsistent, varying widely based on what code executed each iteration. Serial output was causing significant delays and false overrun detections.

**Changes:**

1. **Fixed-rate control loop (1 kHz)**
   - Implemented early-return pattern: loop exits immediately if <1000μs elapsed
   - Ensures consistent dt for PID calculations
   - Added overrun detection (flags iterations >1.5x expected period)

2. **I2C speed increase (100 kHz → 400 kHz)**
   - AS5600 encoder read reduced from ~650μs to ~290μs
   - This was the main bottleneck consuming 65% of loop time

3. **Serial output optimization**
   - Problem: `Serial.print(float, 2)` takes ~500μs per call due to AVR software float formatting
   - Solution: Transmit values as integers (×1000), decode in Julia
   - Further optimization: Use `ltoa()` + manual buffer concatenation instead of `snprintf`
   - Result: Serial output no longer causes overruns

4. **Baud rate increase (115200 → 500000)**
   - Reduces time spent waiting for TX buffer
   - Arduino Nano supports up to 2 Mbaud, but 500k is reliable

**Serial output comparison:**

| Approach | Overruns | Loop Freq | Flash Size |
|---|---|---|---|
| Float Serial.print() ×9 calls | 1065 | 881 Hz | 12,994 B |
| Integer ×1000 Serial.print() ×9 | 0 | 985 Hz | 12,560 B |
| Integer snprintf buffer | 0 | 1001 Hz | 13,904 B |
| Integer ltoa buffer (final) | 0 | 1003 Hz | 12,700 B |

**Final timing results:**
- Loop frequency: 1003 Hz mean (target: 1000 Hz)
- Loop frequency range: 900-1100 Hz
- Overruns: 0

**Parameters:** Kp=0.8, Ki=4.0, Kd=0.015, Filter=100Hz

---

## Next Steps

Timing infrastructure is now solid. Ready to focus on PID tuning with reliable data collection.

---

## Systematic Tuning Approach

1. **Fix bugs first** - ensure system behaves as expected
2. **Collect diagnostic data** - PID terms, state, timing
3. **One parameter at a time** - isolate effects of each change
4. **Quantitative comparison** - use RMS error, balancing time metrics
5. **Document everything** - track what works and what doesn't

---

## Notes

- AccelStepper on Arduino Nano limited to ~4000 steps/sec with `run()`
- Current maxSpeed/acceleration settings (200000/100000) are above this limit but acceleration is high enough to act nearly instant
- Engagement margin of ±25° seems appropriate
- Motor limit of ±90° is a hard constraint due to wiring

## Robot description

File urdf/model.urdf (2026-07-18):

<?xml version="1.0"?>
<robot name="inverted_pendulum">

    <!-- Base (fixed to the world origin) -->
    <link name="base">
        <visual>
            <origin xyz="0 0 0" rpy="0 0 0" />
            <geometry>
                <mesh filename="package://meshes/base.dae" />
            </geometry>
        </visual>
    </link>

    <!-- Arm (actuated by stepper motor) -->
    <link name="arm">
        <inertial>
            <origin xyz="0.041 0 0.011" rpy="0 0 0" />
            <!-- <mass value="0.03477272" /> -->
            <mass value="0.026" />
            <inertia ixx="0.00000429" ixy="0" ixz="-0.00000175" iyy="0.00001756" iyz="0" izz="0.0000173" />
        </inertial>
        <visual>
            <origin xyz="0 0 0" rpy="0 0 0" />
            <geometry>
                <mesh filename="package://meshes/arm.dae" />
            </geometry>
        </visual>
    </link>

    <!-- Pendulum (swings freely on the arm).
         Mass, COM, and inertia from Onshape CAD (custom PLA densities to
         match measured 14 g pendulum mass at the printed infill %s; 2p
         coin modelled; diametric magnet omitted, ~0.3 g near the pivot).
         Cross-checked against sysid free-swing period: m·g·d/ω² gives
         I_axis ≈ 4.48e-5 kg·m², matching m·d² + Lxx = 4.46e-5 within 1%.
         Physical COM confirmed by balance-point measurement: ~51 mm from
         pivot. Measured period: 10 half-swings in 2.45 s → T ≈ 490 ms
         → ω_n ≈ 12.8 rad/s, consistent with model prediction of 500 ms.
         Inertia tensor is about the COM with axes aligned to the link
         frame; swing axis is x (matching the arm_to_pendulum joint).
         The 0.062 x-offset is the link-frame convention from the original
         model (offset along the rotation axis, no swing effect). -->
    <link name="pendulum">
        <inertial>
            <origin xyz="0.062 0 -0.051" rpy="0 0 0" />
            <mass value="0.014" />
            <inertia ixx="0.00000806" ixy="0" ixz="0" iyy="0.00000855" iyz="0.00000019" izz="0.00000061" />
        </inertial>
        <visual>
            <origin xyz="0 0 0" rpy="0 0 0" />
            <geometry>
                <mesh filename="package://meshes/pendulum.dae" />
            </geometry>
        </visual>
    </link>

    <!-- Revolute joint for arm (actuated) -->
    <joint name="base_to_arm" type="revolute">
        <parent link="base" />
        <child link="arm" />
        <origin xyz="0 0 0.075" rpy="0 0 -1.57079" />
        <axis xyz="0 0 1" />
    </joint>

    <!-- Ball joint for pendulum (free swinging) -->
    <joint name="arm_to_pendulum" type="continuous">
        <parent link="arm" />
        <child link="pendulum" />
        <origin xyz="0 0 0.014" rpy="0 0 0" />
        <axis xyz="1 0 0" />
    </joint>

</robot>

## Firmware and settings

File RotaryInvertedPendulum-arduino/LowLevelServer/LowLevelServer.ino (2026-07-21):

#include <FastAccelStepper.h>
#include <AS5600.h>
#include <Wire.h>
#include <util/twi.h>

#include "StepperUtils.h"
#include "firmware_version.h"

// Selects this rig's AS5600 I2C backend (module quality varies — see
// docs/BOM.md and hw_profiles/ in this directory). hw_config.h is
// gitignored and has no safe default; flash_if_needed.py refuses to
// compile without it. It must define:
//   as5600_backend_setup(AS5600 &dev)         — Wire/bus init
//   as5600_backend_wait_magnet(AS5600 &dev)   — startup gate (may be a no-op)
//   as5600_backend_read(AS5600 &dev, long*)   — one RAW_ANGLE read, returns ok
#include "hw_config.h"

// Communication speed
const long BAUD_RATE = 2000000;

// Command bytes
#define CMD_READY 0x01
#define CMD_GET_STATE 0x02
#define CMD_SET_ACCEL 0x03   // was CMD_SET_TARGET (position-mode); now angular accel (rad/s²)
#define CMD_ENGAGE_MOTOR 0x04
#define CMD_DISENGAGE_MOTOR 0x05
#define CMD_TARE_PENDULUM 0x06   // re-zero pen_position_rad to current AS5600 reading
#define CMD_DEBUG_I2C     0x07   // diagnostic: raw I2C read, returns 4 bytes [rc, n, hi, lo]
#define CMD_GET_FIRMWARE_VERSION 0x08   // returns 4-byte hash of the running sketch source

// Pin assignments. STEP must be on pin 9 (Timer1 OC1A on ATmega328) for
// FastAccelStepper. DIR and ENABLE can be any digital pin.
#define DIR_PIN 2
#define STEP_PIN 9
#define ENABLE_PIN 5

// Accel-mode envelope. See pendulum_env.py for the corresponding sim
// constants. The velocity cap below corresponds to MAX_VELOCITY_RAD_S
// = 5 rad/s: 5 × (1600 steps/rev / 2π) ≈ 1273 steps/s ⇒ ~785 µs/step.
const uint32_t MOTOR_MIN_STEP_US = 550;  // ≈ 7 rad/s (was 785 ≈ 5 rad/s)

// Position safety limit (matches MOTOR_SAFE_LIMIT_RAD on the Python side,
// ±125°). Past the rail the firmware actively brakes (commands a fixed
// opposing accel) so the motor decelerates even if the host stops
// sending commands (USB hiccup, host hang). Clamping to zero instead
// would just let moveByAcceleration(0, true) coast the motor past the
// rail at peak velocity.
const int32_t MOTOR_SAFE_LIMIT_STEPS = (int32_t)((125.0f * PI / 180.0f) *
                                                  (1600.0f / (2.0f * PI)));
// Brake authority when past the rail. 150 rad/s² matches the
// pendulum_env.py MAX_ACCEL_RAD_S2 — strong enough to bleed off the
// 5 rad/s vel cap within ~33 ms.
const int32_t MOTOR_BRAKE_ACCEL_STEPS_S2 =
    (int32_t)(150.0f * (1600.0f / (2.0f * PI)));

// Encoder samples are kept in a ring buffer updated at 500 Hz; GET_STATE
// returns velocity computed as (newest - oldest)/Δt over a window of 5
// samples = 4 inter-sample gaps = 8 ms. Window halved from 10 → 5 on
// 2026-05-20 to cut ~9 ms of observation lag — the largest tunable
// component of the rig's policy-loop lag. Tradeoff: ~√2× noisier
// per-sample velocity estimate. See docs/transport_delay.md.
const uint16_t SAMPLE_PERIOD_US = 2000;
const uint8_t  BUFFER_SIZE      = 16;
const uint8_t  VEL_WINDOW       = 5;
// Discard impossibly-large per-sample wraps as I²C glitches. Real
// pendulum tops out at ~50 rad/s, so in one 2 ms sample period the
// raw AS5600 reading can change by at most 50·0.002·4096/(2π) ≈ 65 LSB.
// Anything more is almost certainly a corrupted I²C transaction —
// keep the previous reading rather than letting it pollute the
// accumulator with a spurious ±2π wrap.
const long PEN_RAW_MAX_DELTA_LSB = 500;

static int32_t motor_step_buf[BUFFER_SIZE];   // raw stepper position (steps)
static float   pen_rad_buf[BUFFER_SIZE];      // accumulated pendulum angle (rad)
static uint32_t time_us_buf[BUFFER_SIZE];     // sample timestamps (µs)
static uint8_t  buf_head = 0;                 // next write index
static bool     buf_filled = false;           // becomes true after first full lap
static uint32_t last_sample_us = 0;

// Continuously-tracked pendulum angle (independent of GET_STATE cadence so
// rapid wraparounds aren't missed).
static long    pen_raw_prev   = -1;           // -1 = first read sentinel
static float   pen_position_rad = 0.0f;

// State variables
FastAccelStepperEngine engine = FastAccelStepperEngine();
FastAccelStepper *stepper = NULL;
AS5600 as5600;

// `motor_engaged` is only touched from loop() / handleCommand() — no ISR
// access — so `volatile` would only mislead future readers. Plain bool.
bool motor_engaged = false;

// Host-liveness watchdog. Without it, a killed/hung host process leaves
// moveByAcceleration() applying the LAST commanded accel forever — the
// motor winds up to the velocity cap and stalls against the mechanical
// hard stop under full torque (incident 2026-07-05: fried the Nano's
// CH340 and the host PC's USB-port ESD protection). The position-limit
// brake in CMD_SET_ACCEL can't help: it only runs when a command
// arrives.
//
// Armed by the first CMD_SET_ACCEL after an engage (so the idle gap
// between CMD_ENGAGE_MOTOR and the control loop's first tick can't
// false-trigger), refreshed by every received command, disarmed on
// engage/disengage. When armed and no command has arrived for
// WATCHDOG_TIMEOUT_US, loop() force-stops and disengages the motor —
// same path as CMD_DISENGAGE_MOTOR. The host re-engages on the next
// episode/run start, so recovery is automatic.
//
// 200 ms = 7-10 consecutive missed ticks at the 35-50 Hz control rates
// this rig uses — far beyond any legitimate host pause during an active
// episode, far shorter than a wind-up into the hard stop matters.
const uint32_t WATCHDOG_TIMEOUT_US = 200000UL;
static uint32_t last_cmd_us = 0;
static bool watchdog_armed = false;

// Function prototypes
void handleCommand();
void sendState();
void sampleState();
void computeVelocities(float* motor_vel_rad_s, float* pen_vel_rad_s);

void setup()
{
    Serial.begin(BAUD_RATE);

    as5600_backend_setup(as5600);

    engine.init();
    stepper = engine.stepperConnectToPin(STEP_PIN);
    if (!stepper)
    {
        while (true) { /* halt: STEP_PIN is not Timer1 OC1A/OC1B */ }
    }
    stepper->setDirectionPin(DIR_PIN);
    stepper->setEnablePin(ENABLE_PIN);
    stepper->setAutoEnable(false);

    int8_t rc_speed = stepper->setSpeedInUs(MOTOR_MIN_STEP_US);
    if (rc_speed != 0)
    {
        while (true) {}
    }
    stepper->setForwardPlanningTimeInMs(8);
    stepper->disableOutputs();

    while (!Serial) { ; }
    as5600_backend_wait_magnet(as5600);
    last_sample_us = micros();
}

void loop()
{
    uint32_t now_us = micros();
    if ((uint32_t)(now_us - last_sample_us) >= SAMPLE_PERIOD_US)
    {
        last_sample_us = now_us;
        sampleState();
    }
    if (Serial.available() > 0)
    {
        handleCommand();
    }
    // Host-liveness watchdog: if the host went quiet mid-episode, stop
    // the motor instead of executing its last accel command forever.
    // Timestamp taken fresh here (not the `now_us` from the top of loop())
    // because handleCommand() above may have just refreshed last_cmd_us
    // via its own micros() call — comparing against the stale, earlier
    // now_us would make (now_us - last_cmd_us) underflow (unsigned) into
    // a huge value on the very tick that arms the watchdog, instantly
    // self-tripping before the motor ever gets to move.
    uint32_t watchdog_check_us = micros();
    if (motor_engaged && watchdog_armed &&
        (uint32_t)(watchdog_check_us - last_cmd_us) > WATCHDOG_TIMEOUT_US)
    {
        motor_engaged = false;
        watchdog_armed = false;
        stepper->forceStop();
        stepper->disableOutputs();
    }
}

/*
 * Append a (time, motor_position, pendulum_position) sample to the ring
 * buffer and update the pendulum wraparound accumulator.
 */
void sampleState()
{
    int32_t motor_step = stepper->getCurrentPosition();
    // Backend-specific read (see hw_config.h / hw_profiles/) — timing
    // precautions like Timer1 masking, if the backend needs them, are
    // internal to as5600_backend_read().
    long raw = 0;
    bool i2c_ok = as5600_backend_read(as5600, &raw);

    // Pendulum wraparound tracking — only update on successful I²C reads.
    // A failed read (i2c_ok=false) keeps pen_raw_prev unchanged so the next
    // successful read computes a valid delta from the last known good position.
    // Feeding raw=0 (failure sentinel) into the accumulator when pen_raw_prev
    // is non-zero produces a spurious −14° step that corrupts every subsequent
    // observation.
    if (i2c_ok)
    {
        if (pen_raw_prev < 0)
        {
            pen_raw_prev = raw;
        }
        else
        {
            long delta = raw - pen_raw_prev;
            if (delta >  2048) delta -= 4096;
            if (delta < -2048) delta += 4096;
            if (delta > PEN_RAW_MAX_DELTA_LSB || delta < -PEN_RAW_MAX_DELTA_LSB)
            {
                pen_raw_prev = raw;
            }
            else
            {
                pen_position_rad += (float)delta * ((2.0f * PI) / 4096.0f);
                pen_raw_prev = raw;
            }
        }
    }

    motor_step_buf[buf_head] = motor_step;
    pen_rad_buf[buf_head]    = pen_position_rad;
    time_us_buf[buf_head]    = last_sample_us;
    buf_head = (buf_head + 1) % BUFFER_SIZE;
    if (buf_head == 0) buf_filled = true;
}

/*
 * Compute velocity over the most recent VEL_WINDOW samples as
 * (newest - oldest)/Δt. Returns 0 until the buffer holds enough samples.
 */
void computeVelocities(float* motor_vel_rad_s, float* pen_vel_rad_s)
{
    uint8_t n_samples = buf_filled ? BUFFER_SIZE : buf_head;
    if (n_samples < VEL_WINDOW)
    {
        *motor_vel_rad_s = 0.0f;
        *pen_vel_rad_s   = 0.0f;
        return;
    }

    uint8_t newest = (uint8_t)((buf_head + BUFFER_SIZE - 1)            % BUFFER_SIZE);
    uint8_t oldest = (uint8_t)((buf_head + BUFFER_SIZE - VEL_WINDOW)   % BUFFER_SIZE);

    uint32_t t_new = time_us_buf[newest];
    uint32_t t_old = time_us_buf[oldest];
    float dt_s = (float)((uint32_t)(t_new - t_old)) * 1e-6f;
    if (dt_s <= 0.0f)
    {
        *motor_vel_rad_s = 0.0f;
        *pen_vel_rad_s   = 0.0f;
        return;
    }

    int32_t motor_step_delta = motor_step_buf[newest] - motor_step_buf[oldest];
    *motor_vel_rad_s = ((float)motor_step_delta * ((2.0f * PI) / 1600.0f)) / dt_s;

    float pen_delta = pen_rad_buf[newest] - pen_rad_buf[oldest];
    *pen_vel_rad_s = pen_delta / dt_s;
}

/*
 * Handle incoming commands.
 */
void handleCommand()
{
    uint8_t command = Serial.read();

    // Any received byte proves the host is alive — refresh the watchdog.
    last_cmd_us = micros();

    switch (command)
    {
    case CMD_READY:
        Serial.write(CMD_READY);
        break;

    case CMD_GET_STATE:
        sendState();
        break;

    case CMD_SET_ACCEL:
        {
            // Read 4 bytes (size of float) with a short timeout. If a byte
            // gets dropped — UART overrun under stepper EMI, or a flipped
            // command byte that desyncs the parser — readBytes returns
            // short and we bail. The next command re-syncs.
            Serial.setTimeout(5);
            float accel_rad_s2;
            size_t n = Serial.readBytes((char *)&accel_rad_s2, sizeof(float));
            Serial.setTimeout(1000);  // restore Stream default
            if (n != sizeof(float)) break;

            if (!motor_engaged) break;

            // Convert rad/s² to steps/s² (1600 microsteps per revolution).
            // moveByAcceleration takes int32_t.
            int32_t accel_steps_s2 =
                (int32_t)(accel_rad_s2 * (1600.0f / (2.0f * PI)));

            // Position-limit safety: past the rail, ignore the host's
            // command and actively brake instead. Just zeroing accel here
            // is dangerous — with allow_reverse=true, an accel of 0 means
            // "hold current speed", so a motor at +5 rad/s heading
            // outbound would coast indefinitely if the host went quiet.
            // Brake with a fixed opposing accel so we decelerate
            // regardless of host liveness.
            int32_t cur_pos = stepper->getCurrentPosition();
            if (cur_pos >= MOTOR_SAFE_LIMIT_STEPS)
            {
                accel_steps_s2 = -MOTOR_BRAKE_ACCEL_STEPS_S2;
            }
            else if (cur_pos <= -MOTOR_SAFE_LIMIT_STEPS)
            {
                accel_steps_s2 = +MOTOR_BRAKE_ACCEL_STEPS_S2;
            }

            // allow_reverse=true makes the library decelerate smoothly through
            // zero when the sign of accel opposes the current velocity — no
            // state machine needed on our side.
            stepper->moveByAcceleration(accel_steps_s2, true);

            // First accel command of this engagement: the control loop is
            // live, arm the watchdog.
            watchdog_armed = true;
        }
        break;

    case CMD_ENGAGE_MOTOR:
        motor_engaged = true;
        watchdog_armed = false;  // armed by the first CMD_SET_ACCEL
        stepper->enableOutputs();
        // Start in zero-accel state. moveByAcceleration(0, true) means
        // "hold current speed", and since we've just enabled the driver
        // the stepper is at rest — so this leaves it at rest until the
        // host sends its first CMD_SET_ACCEL.
        // Note: ENGAGE does not re-zero `getCurrentPosition()` or
        // `pen_position_rad`. Position counters persist across
        // engage/disengage cycles (and across episodes) by design — the
        // host is responsible for tracking the frame.
        stepper->moveByAcceleration(0, true);
        break;

    case CMD_DISENGAGE_MOTOR:
        motor_engaged = false;
        watchdog_armed = false;
        // forceStop() drains the Timer1 step queue immediately; without this,
        // queued steps would continue advancing the firmware position counter
        // even though the driver's enable pin is HIGH.
        stepper->forceStop();
        stepper->disableOutputs();
        break;

    case CMD_TARE_PENDULUM:
        // Re-zero pen_position_rad to the current AS5600 reading. Used by
        // real_env.reset() after the pendulum has settled at rest so that
        // each fine-tune episode samples a fresh bias from the rig's
        // static-friction-bounded rest distribution (±1.9°). Without this,
        // all fine-tune episodes share the firmware-boot bias and the
        // policy overfits to that single calibration offset.
        //
        // Shift pen_position_rad AND every entry in pen_rad_buf by the
        // current pen_position_rad. The buffer's relative deltas (used
        // by computeVelocities) are preserved, so velocity calculation
        // continues uninterrupted across the tare. Disable interrupts so
        // sampleState() doesn't run mid-update with a partially-shifted
        // buffer.
        noInterrupts();
        {
            float offset = pen_position_rad;
            for (uint8_t i = 0; i < BUFFER_SIZE; i++)
            {
                pen_rad_buf[i] -= offset;
            }
            pen_position_rad = 0.0f;
        }
        interrupts();
        Serial.write(CMD_TARE_PENDULUM);  // ack
        break;

    case CMD_GET_FIRMWARE_VERSION:
        {
            // Lets the host tell "this Nano already has the exact sketch
            // I'd flash" apart from "stale/wrong/blank" without actually
            // reflashing — see gen_firmware_version.py and
            // tools/pi_demo/flash_if_needed.py.
            uint32_t version = FIRMWARE_VERSION_HASH;
            Serial.write((byte *)&version, sizeof(version));
        }
        break;

    case CMD_DEBUG_I2C:
        {
            // Repeated-START read with diagnostics. Short delay ensures
            // ≥200 µs bus-free time after any preceding sampleState() STOP.
            // Returns 4 bytes: [endTransmission_rc, requestFrom_n, raw_hi, raw_lo]
            delayMicroseconds(200);
            uint8_t et_rc, rf_n;
            uint16_t raw16 = 0;
            uint8_t saved = TIMSK1;
            TIMSK1 &= ~(_BV(OCIE1A) | _BV(TOIE1));
            Wire.beginTransmission(0x36);
            Wire.write(0x0C);
            et_rc = (uint8_t)Wire.endTransmission(false);
            if (et_rc == 0)
            {
                rf_n = (uint8_t)Wire.requestFrom((uint8_t)0x36, (uint8_t)2);
                if (rf_n == 2)
                {
                    raw16 = ((uint16_t)Wire.read() << 8) | Wire.read();
                    raw16 &= 0x0FFF;
                }
            }
            else
            {
                rf_n = 0;
            }
            TIMSK1 = saved;
            Serial.write(et_rc);
            Serial.write(rf_n);
            Serial.write((uint8_t)(raw16 >> 8));
            Serial.write((uint8_t)(raw16 & 0xFF));
        }
        break;

    default:
        break;
    }
}

/*
 * Send the current state of the system:
 * - Current time in microseconds   (4 bytes, uint32)
 * - Stepper motor position in rad  (4 bytes, float)
 * - Pendulum position in rad       (4 bytes, float)
 * - Stepper motor velocity in rad/s (4 bytes, float)
 * - Pendulum velocity in rad/s     (4 bytes, float)
 */
void sendState()
{
    // Take the most recent buffer entry as the instantaneous position,
    // and compute velocity from the (newest - oldest)/Δt regression
    // window. The timestamp is the sample time of `newest` — not a
    // fresh micros() — so the host gets a self-consistent (t, pos, vel)
    // tuple it can time-align without inheriting up-to-one-sample of
    // bias.
    uint8_t newest = (uint8_t)((buf_head + BUFFER_SIZE - 1) % BUFFER_SIZE);
    uint32_t current_time = time_us_buf[newest];
    float motor_position_radians = stepsToRadians(motor_step_buf[newest]);
    float pendulum_position_radians = pen_rad_buf[newest];

    float motor_velocity_rad_s, pendulum_velocity_rad_s;
    computeVelocities(&motor_velocity_rad_s, &pendulum_velocity_rad_s);

    // Flip the signs of the motor and pendulum positions / velocities to
    // match the sim-frame convention the Python clients expect.
    motor_position_radians    *= -1;
    pendulum_position_radians *= -1;
    motor_velocity_rad_s      *= -1;
    pendulum_velocity_rad_s   *= -1;

    // Pack and send the data
    Serial.write((byte *)&current_time, sizeof(current_time));
    Serial.write((byte *)&motor_position_radians, sizeof(motor_position_radians));
    Serial.write((byte *)&pendulum_position_radians, sizeof(pendulum_position_radians));
    Serial.write((byte *)&motor_velocity_rad_s, sizeof(motor_velocity_rad_s));
    Serial.write((byte *)&pendulum_velocity_rad_s, sizeof(pendulum_velocity_rad_s));
}

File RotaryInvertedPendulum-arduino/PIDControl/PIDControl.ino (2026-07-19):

/**
 * PIDControl.ino - Self-contained PID balancing controller for rotary inverted pendulum
 *
 * ARCHITECTURE OVERVIEW
 * ---------------------
 * This sketch runs a complete pendulum balancing system on an Arduino Nano without
 * requiring a computer connection. The control loop runs at a fixed 1 kHz rate.
 *
 * State Machine:
 *   WAITING   - Motor disabled, waiting for pendulum to be lifted near vertical
 *   BALANCING - Motor engaged, PID actively controlling to keep pendulum upright
 *
 * Control Flow (each 1ms iteration):
 *   1. Read encoder via I2C (AS5600, 400 kHz)
 *   2. Apply low-pass filter to angle
 *   3. Compute PID output (P + I + D terms)
 *   4. Update motor target position
 *   5. Run AccelStepper to move toward target
 *
 * TIMING DESIGN
 * -------------
 * - Control loop: Fixed 1 kHz (1000 μs period). If loop() is called before 1ms has
 *   elapsed, it returns immediately without doing work. This ensures consistent dt.
 * - I2C clock: 400 kHz (vs default 100 kHz) - reduces encoder read from 650μs to 290μs
 * - Serial output: 100 Hz (every 10ms), uses buffered integer output to avoid blocking
 * - Overrun detection: Flags iterations that exceed 1.5x expected period
 *
 * SERIAL OUTPUT FORMAT
 * --------------------
 * When enabled (press 'P'), outputs CSV at 100 Hz:
 *   motor_pos, motor_target, pendulum×1000, state, P×1000, I×1000, D×1000, freq_hz, overruns
 *
 * Values are transmitted as integers (×1000) to avoid slow float-to-string conversion.
 * The companion Julia script (collect_and_plot.jl) divides by 1000 when parsing.
 *
 * Why integers? Serial.print(float) takes ~500μs on Arduino Nano (ATmega328P) because
 * there's no hardware floating-point unit, so float-to-string conversion is done in
 * slow software. Using ltoa() with integers takes ~50μs instead, preventing overruns.
 *
 * MOTOR CENTERING
 * ---------------
 * To prevent the motor from drifting to its ±90° limits, we bias the pendulum target
 * angle based on motor position: target = upright + K_MOTOR_CENTERING * motor_pos
 *
 * This creates a slight tilt that naturally pushes the motor back toward center.
 * The bias is small enough (~0.6° per 30° motor offset) to not destabilize balancing.
 */

#include <AccelStepper.h>
#include <AS5600.h>
#include <Wire.h>

// =============================================================================
// PIN DEFINITIONS
// =============================================================================
const int DIR_PIN = 2;
const int STEP_PIN = 9;     // Timer1 OC1A (kept on this pin so FastAccelStepper-based sketches work too)
const int ENABLE_PIN = 5;

// =============================================================================
// HARDWARE CONSTANTS
// =============================================================================
const long STEPS_PER_REVOLUTION = 200 * 8;  // 200 steps * 8 microsteps = 1600
const float DEGREES_PER_STEP = 360.0f / STEPS_PER_REVOLUTION;
const float STEPS_PER_DEGREE = STEPS_PER_REVOLUTION / 360.0f;

// =============================================================================
// COMMUNICATION SETTINGS
// =============================================================================
const long SERIAL_BAUD_RATE = 500000;      // High speed for data collection
const long I2C_CLOCK_HZ = 400000;          // Fast mode I2C (vs 100kHz default)

// =============================================================================
// MOTOR SETTINGS
// =============================================================================
// AccelStepper on Arduino Nano is limited to ~4000 steps/sec due to step pulse
// timing overhead. High acceleration ensures motor reaches max speed in ~40ms
// (4000 / 100000 = 0.04s), which is fast compared to typical balance recovery.
const long MOTOR_MAX_SPEED = 4000;         // steps/sec (practical limit on Nano)
const long MOTOR_ACCELERATION = 100000;    // steps/sec² (high = instant response)

// =============================================================================
// CONTROL PARAMETERS (tune these)
// =============================================================================
//
// TUNING GUIDE - Recommended order:
//   1. K_MOTOR_CENTERING - Prevent motor drift to limits
//   2. Kp - Get basic responsiveness (start low, increase until oscillation)
//   3. Kd - Add damping to reduce oscillation
//   4. Ki - Eliminate steady-state error (use sparingly)
//   5. ENGAGEMENT_MARGIN_DEG - Adjust catch window if needed
//   6. Fine-tune limits (INTEGRAL_LIMIT, PID_OUTPUT_LIMIT_DEG)
//
// =============================================================================

// PID gains
// -----------------------------------------------------------------------------
// Kp (Proportional): Reacts to current error
//   - Increase if: pendulum responds too slowly, falls before correcting
//   - Decrease if: pendulum oscillates rapidly, motor is jerky
//   - Typical range: 0.5 - 2.0
const float Kp = 0.30f;

// Ki (Integral): Accumulates error over time, eliminates steady-state offset
//   - Increase if: pendulum settles with persistent tilt
//   - Decrease if: motor drifts, overshoots, or oscillates slowly
//   - Typical range: 1.0 - 6.0 (use sparingly, often the cause of drift)
const float Ki = 0.1f;

// Kd (Derivative): Reacts to rate of change, provides damping
//   - Increase if: pendulum oscillates, needs more damping
//   - Decrease if: motor is jerky or reacts to noise
//   - Typical range: 0.005 - 0.05
const float Kd = 0.005f;

// Filter cutoff for derivative calculation
// -----------------------------------------------------------------------------
//   - Increase if: response feels sluggish
//   - Decrease if: derivative term is noisy/jerky
//   - Must be less than half of CONTROL_FREQUENCY_HZ (Nyquist)
const float FILTER_CUTOFF_HZ = 150.0f;

// Motor centering - prevents motor from drifting to position limits
// -----------------------------------------------------------------------------
// Biases pendulum target angle based on motor position to push motor back
// Effect: motor_pos * K = degrees of pendulum tilt toward center
//   - Increase if: motor drifts toward ±90° limits during balancing
//   - Decrease if: centering interferes with balancing (causes oscillation)
//   - At 0.05: 30° motor offset → 1.5° pendulum tilt toward center
//   - At 0.10: 30° motor offset → 3.0° pendulum tilt toward center
//   - Typical range: 0.03 - 0.15
const float K_MOTOR_CENTERING = 0.05f;

// Engagement window - how close to vertical before engaging motor
// -----------------------------------------------------------------------------
//   - Increase if: want to catch pendulum earlier, more aggressive recovery
//   - Decrease if: controller struggles when pendulum is far from vertical
//   - Typical range: 15 - 40 degrees
const float ENGAGEMENT_MARGIN_DEG = 25.0f;
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

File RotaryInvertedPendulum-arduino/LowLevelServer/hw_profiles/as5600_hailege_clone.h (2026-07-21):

// AS5600 I2C backend: Hailege clone module.
//
// This clone's I2C behavior degrades badly under the standard AS5600
// library (Wire, interrupt-driven, 400 kHz) combined with FastAccelStepper's
// Timer1 ISR — see docs/BOM.md's "Amazon France (as-built sourcing)"
// listing ("behaves differently from the original Seeed module"). This
// backend instead:
//   - Recovers a possibly-stuck I2C bus at boot (9 SCL pulses + manual
//     STOP) — a reset mid-transaction can leave this module holding the
//     bus.
//   - Reads the RAW_ANGLE register via direct polling TWI register
//     access instead of the Wire library, bypassing its interrupt-driven
//     state machine entirely (eliminates sensitivity to Timer1 ISR
//     preemption), with retries.
//   - Runs the bus at 100 kHz instead of 400 kHz (400 kHz bits get
//     corrupted by the Timer1 ISR on this module).
//   - Skips the isConnected()/detectMagnet() startup gate: both rely on
//     an I2C write-only probe that's unreliable on this clone, while
//     direct RAW_ANGLE reads work correctly. The host validates state
//     values before engaging the motor.
//
// To use this profile: copy this file to ../hw_config.h (gitignored —
// see tools/pi_demo/README.md and flash_if_needed.py, which refuses to
// compile without it).

#define AS5600_I2C_ADDR  0x36
#define AS5600_RAW_REG   0x0C
#define AS5600_MAX_RETRIES 3

static void as5600_backend_setup(AS5600 &dev)
{
    // I²C bus recovery: always runs regardless of SDA state. After an
    // Arduino reset mid-transaction the AS5600 may be holding SDA LOW
    // (mid-byte) or HIGH (waiting for ACK) — both leave it unable to
    // respond to a fresh Wire.begin(). Nine SCL pulses let the slave
    // finish any in-progress byte. The STOP is generated cleanly by
    // driving SDA LOW while SCL is still LOW (end of last pulse), then
    // raising SCL HIGH, then raising SDA HIGH — avoiding the spurious
    // START that occurs if SDA goes LOW while SCL is already HIGH.
    {
        const uint8_t SDA_PIN = A4, SCL_PIN = A5;
        pinMode(SCL_PIN, OUTPUT);
        pinMode(SDA_PIN, INPUT_PULLUP);
        for (uint8_t i = 0; i < 9; i++) {
            digitalWrite(SCL_PIN, HIGH); delayMicroseconds(5);
            digitalWrite(SCL_PIN, LOW);  delayMicroseconds(5);
        }
        // SCL is now LOW. Drive SDA LOW while SCL LOW (not a START).
        // Then raise SCL HIGH, then SDA HIGH = clean STOP condition.
        pinMode(SDA_PIN, OUTPUT);
        digitalWrite(SDA_PIN, LOW);  delayMicroseconds(5);
        digitalWrite(SCL_PIN, HIGH); delayMicroseconds(5);
        digitalWrite(SDA_PIN, HIGH); delayMicroseconds(5);
        pinMode(SCL_PIN, INPUT);
        pinMode(SDA_PIN, INPUT);
        delay(10);
    }

    Wire.begin();
    Wire.setClock(100000);  // 100 kHz: 400 kHz bits (2.5 µs) get corrupted by
                            // FastAccelStepper Timer1 ISR; 100 kHz (10 µs/bit)
                            // is robust within the 2 ms sampleState() budget.
    dev.begin();
    // No startup gate on isConnected()/detectMagnet(): both rely on an I²C
    // write-only probe that is unreliable on this module clone, while
    // rawAngle() reads work correctly. The host validates state values before
    // engaging the motor.
}

static void as5600_backend_wait_magnet(AS5600 &dev)
{
    // No-op: see as5600_backend_setup()'s comment.
    (void)dev;
}

// Direct polling TWI read for AS5600 RAW_ANGLE register.
// Bypasses the Wire library's interrupt-driven state machine entirely,
// which eliminates sensitivity to Timer1 ISR preemption. Retries up to
// AS5600_MAX_RETRIES times (each retry adds ~100 µs for the NACK+delay).
// Masks Timer1 interrupts for the ~500 µs read window to avoid any
// preemption of the busy-wait loops; also suspends the Wire ISR so it
// doesn't race with this direct register access.
static bool as5600_backend_read(AS5600 &dev, long* out)
{
    (void)dev;
    uint8_t saved_timsk1 = TIMSK1;
    TIMSK1 = 0;

    uint8_t saved_twcr_twie = TWCR & _BV(TWIE);
    TWCR &= ~_BV(TWIE);

    bool ok = false;
    for (uint8_t attempt = 0; attempt < AS5600_MAX_RETRIES && !ok; attempt++)
    {
        if (attempt > 0) delayMicroseconds(150);

        uint16_t to;

        // START
        TWCR = _BV(TWINT) | _BV(TWSTA) | _BV(TWEN);
        for (to = 20000; to && !(TWCR & _BV(TWINT)); to--);
        if (!to || (TWSR & 0xF8) != TW_START) goto stop_retry;

        // SLA+W
        TWDR = AS5600_I2C_ADDR << 1;
        TWCR = _BV(TWINT) | _BV(TWEN);
        for (to = 20000; to && !(TWCR & _BV(TWINT)); to--);
        if (!to || (TWSR & 0xF8) != TW_MT_SLA_ACK) goto stop_retry;

        // Register address
        TWDR = AS5600_RAW_REG;
        TWCR = _BV(TWINT) | _BV(TWEN);
        for (to = 20000; to && !(TWCR & _BV(TWINT)); to--);
        if (!to || (TWSR & 0xF8) != TW_MT_DATA_ACK) goto stop_retry;

        // Repeated START
        TWCR = _BV(TWINT) | _BV(TWSTA) | _BV(TWEN);
        for (to = 20000; to && !(TWCR & _BV(TWINT)); to--);
        if (!to || (TWSR & 0xF8) != TW_REP_START) goto stop_retry;

        // SLA+R
        TWDR = (AS5600_I2C_ADDR << 1) | 1;
        TWCR = _BV(TWINT) | _BV(TWEN);
        for (to = 20000; to && !(TWCR & _BV(TWINT)); to--);
        if (!to || (TWSR & 0xF8) != TW_MR_SLA_ACK) goto stop_retry;

        // Read high byte (ACK)
        TWCR = _BV(TWINT) | _BV(TWEN) | _BV(TWEA);
        for (to = 20000; to && !(TWCR & _BV(TWINT)); to--);
        if (!to) goto stop_retry;
        {
            uint8_t hi = TWDR;
            // Read low byte (NACK — last byte)
            TWCR = _BV(TWINT) | _BV(TWEN);
            for (to = 20000; to && !(TWCR & _BV(TWINT)); to--);
            if (!to) goto stop_retry;
            uint8_t lo = TWDR;
            *out = ((long)hi << 8 | lo) & 0x0FFF;
            ok = true;
        }

        stop_retry:
        // Always send STOP to release the bus before next attempt or exit.
        TWCR = _BV(TWINT) | _BV(TWSTO) | _BV(TWEN);
        // Wait for STOP to complete (TWSTO clears itself when done).
        for (uint16_t w = 10000; w && (TWCR & _BV(TWSTO)); w--);
    }

    // Restore Wire ISR
    if (saved_twcr_twie) TWCR |= _BV(TWIE);
    TIMSK1 = saved_timsk1;
    return ok;
}

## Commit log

2026-06-30 docs(electronics): Standardize DRV8825 Vref setting to 0.45 V
2026-07-18 1. feat(arduino): direct-polling AS5600 I2C, bus recovery, host-liveness watchdog
    — LowLevelServer.ino, TestEncoder.ino
    2. chore(arduino): I2C/Timer1/serial diagnostic sketches
    — les 6 Diag*.ino + TestSerial2M.ino
    3. feat(rl): frame stacking, upright-start curriculum, parallel SubprocVecEnv training
    — frame_stack.py, curriculum_train.py, pendulum_env.py, real_env.py, run_policy.py, train_sac.py, finetune_async.py,
    async_control.py
    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
    [model.urdf, system-without-batteries-reinforced-protection-matrix.csv]
2026-07-19 Sync niveau2 from main (ede72e8a8b)
    [arm.stl, base.stl, lid.stl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]
2026-07-21 feat(demo): add unattended cross-platform auto-demo launcher
    Makes the "power it on, walk away" demo robust to any order/delay in
    plugging in Pi power, the pendulum's 12V, and the Nano's USB cable.
    - LowLevelServer.ino: CMD_GET_FIRMWARE_VERSION (0x08) reports a hash of
    the running sketch (gen_firmware_version.py), so a host can skip
    reflashing when the Nano already has the right firmware.
    - lowlevel_client.py: get_firmware_version() to query it.
    - tools/pi_demo/: run_demo.py orchestrates USB discovery (by VID:PID via
    pyserial, not a udev rule or fixed device path), flash-if-needed, and a
    software-only 12V-present check (small accel pulse + AS5600 delta, no
    new sensing hardware) be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
    [LowLevelServer.ino, lowlevel_client.py]
2026-07-21 feat(rig): separate per-rig/per-fork config from shared code
    Addresses collision points that would block a clean PR upstream:
    sysid friction, USB chip vid/pid, and AS5600 I2C backend all vary by
    physical rig/component sourcing (see docs/BOM.md's two build listings),
    and were previously either a single always-tracked file or a value
    hardcoded in shared source.
    - sysid_params.json: gitignored (this rig's live measurement). Versioned
    reference values move to sysid_profiles/ (aliexpress_uk.json = the
    original author's real measurement, amazon_fr.json = this rig's).
    pendulum_env.py falls back to sysid_profiles/aliexpress_uk.json with a
    loud warning if the live file is missing, instead of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
    [LowLevelServer.ino, as5600_hailege_clone.h, curriculum_train.py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]
2026-07-25 chore(rl): add fine-tuned balance policy after bearing replacement
2026-07-25 chore(rl): update balance policy with new fine-tuning after bearing replacement
2026-07-27 docs: add step-by-step Raspberry Pi 3B+ setup guide for the demo
    Covers SD card flashing, headless SSH setup, arduino-cli/Python deps,
    hw_config.h selection, USB detection, and wiring tools/pi_demo/run_demo.py
    into a systemd service so 12V/USB/Pi power can be plugged in any order.
2026-07-27 docs: translate Raspberry Pi setup guide to English, wire into demo sync
    Also register docs/raspberry_pi_setup.md in sync_fork_branches.py's
    LEVEL5_FILES so it ships in the demo branch alongside the other
    pi_demo-facing docs.
2026-07-27 fix(arduino): regenerate stale firmware_version.h hash
2026-07-27 fix(rl): match sim-augmentation env's frame_stack to the teacher being distilled
    [distill.py]
2026-07-29 perf(demo): reuse one Nano connection + in-process policy calls, default to a torch-free student
    run_demo.py loaded the policy and reopened a fresh serial connection to
    the Nano (resetting it, ~2s) on every single demo cycle, and shelled out
    to run_policy.py as a brand new subprocess each time, re-paying torch's
    import cost. Refactor run_policy.py's loading/loop logic into load_policy()
    / run_control_loop() so run_demo.py can call them in-process, load the
    policy once, and keep one connection open across every cycle — only
    reconnecting/reflashing if something actually breaks. Also add
    numpy_student.py + export_weights_numpy.py so the default checkpoint
    (student_numpy.npz, bit-exact to stud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
    [distill.py, export_weights_numpy.py, numpy_student.py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]
2026-07-29 docs: document the frame-stacking x fine-tuning 2x2 across the four demo checkpoints
2026-07-29 Revert "feat(rl): offscreen MuJoCo video recording via train_sac.py --eval --record-video"
    This reverts commit b87e508bccb88174587e3e78454cbf4b020b38ac.
    [pendulum_env.py, train_sac.py]
